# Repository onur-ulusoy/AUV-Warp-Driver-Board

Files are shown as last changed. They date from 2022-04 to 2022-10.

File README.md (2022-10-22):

# WARP Driver Board Hardware 

WARP is the dedicated motor driver and power distribution board that powers our Autonomous Underwater Vehicle (AUV). This advanced board translates high-level navigation commands into precise motor controls, while simultaneously organizes an efficient and safe power distribution network. Its built-in monitoring system and safety features provide robust defenses against potential electrical failures, ensuring the AUV can withstand the challenging underwater environment.

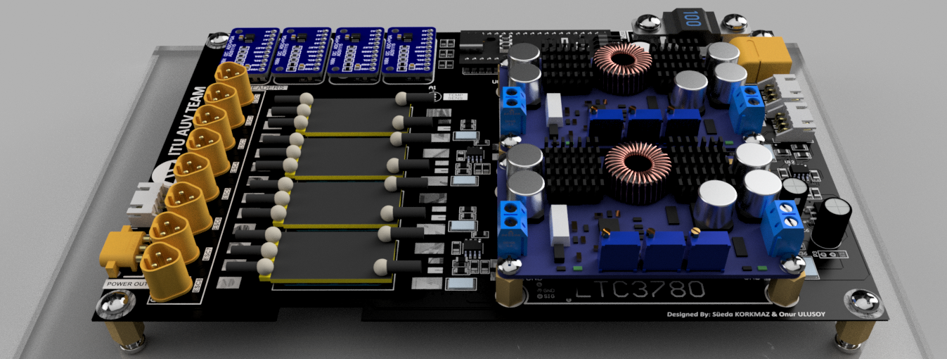
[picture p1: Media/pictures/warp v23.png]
warp
<picture>    </picture>

This repository focuses Warp's hardware design. For more details on the firmware, visit the [Warp Firmware Repository](https://github.com/onur-ulusoy/auv-warp-firmware).

<picture>   dash </picture>

<p align="center">
    <a href="https://auv.itu.edu.tr/">
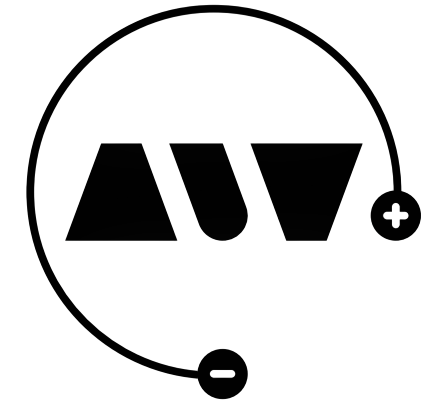
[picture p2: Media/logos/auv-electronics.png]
        
    </a>
</p>

<p align="center"><em >AUV Electronics 2022</em></p>

<picture>   dash </picture>

<p align="center">
    <a href="https://auv.itu.edu.tr/">
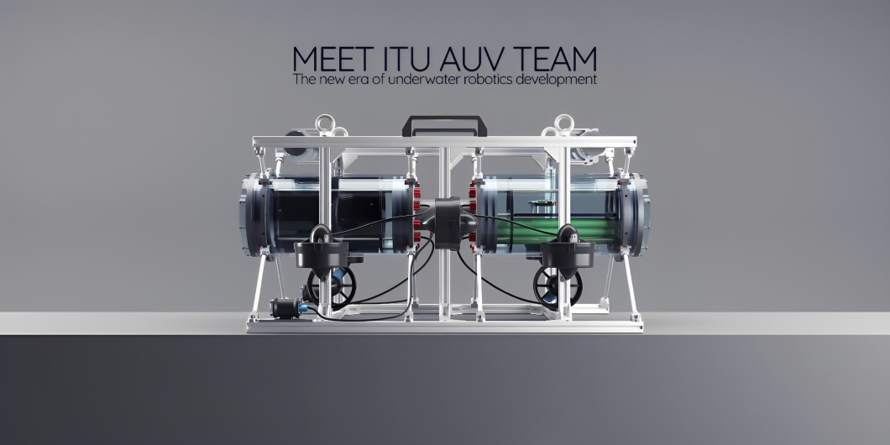
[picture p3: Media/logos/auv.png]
        
    </a>
</p>

<picture>   dash </picture>

<p align="center">
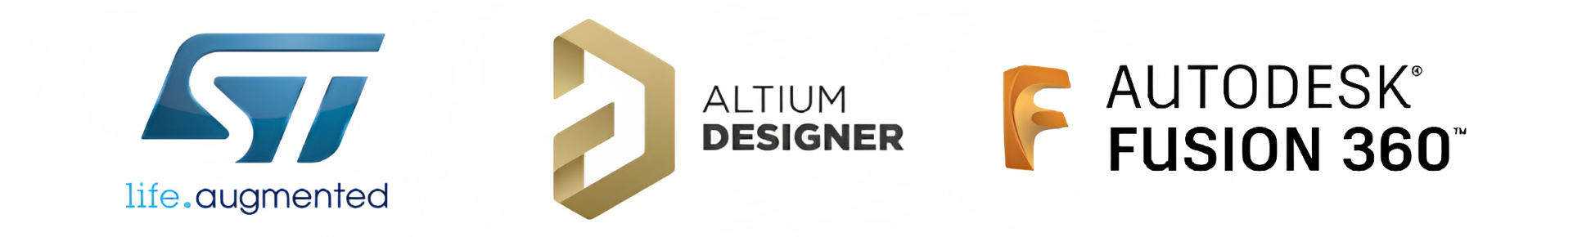
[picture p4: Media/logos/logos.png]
    
</p>

<picture>   dash </picture>

## Table of Contents
- [WARP Driver Board Hardware](#warp-driver-board-hardware)
  - [Table of Contents](#table-of-contents)
  - [Board Description](#board-description)
  - [Electronics Design](#electronics-design)
    - [Layer Structure](#layer-structure)
    - [Primary Stage Protection](#primary-stage-protection)
    - [Secondary Stage Protection](#secondary-stage-protection)
    - [Microcontroller](#microcontroller)
    - [Power Distribution](#power-distribution)
    - [Connections and Monitoring](#connections-and-monitoring)
    - [Cooling and ESC Integration](#cooling-and-esc-integration)
  - [Mechanical Architecture](#mechanical-architecture)
  - [Manufacturing](#manufacturing)
  - [Technologies Used](#technologies-used)
  - [Project Timeline](#project-timeline)
  - [License](#license)
  - [Gallery](#gallery)

## Board Description

The Warp Driver Board manages the direction movements of the underwater vehicle. It controls the brushless AC motors, connected to the propellers known as Thrusters, with PWM signals via integrated circuits called ESCs, based on commands received from the vehicle's onboard computer NVDIA Jetson Xavier. The commands are transmitted from the computer to the main board, then to the driver board, with the conversion of the UART signal to RS232 signal in the form of protobuf encrypted data.

The secondary, but equally crucial, function of the Warp Driver Board is to manage power distribution. It stabilizes the 14-16 Volt input from the battery and provides steady 12V and 5V outputs to other electronic components, the onboard computer, and various peripherals. The Warp Driver Board also includes a secondary 5V regulator to control the voltage supplied to its onboard microcontroller. 

The board is designed with safety and efficiency in mind. It includes a 100A fuse at the battery input and can measure current/voltage in various areas using integrated ADCs, thereby shutting down the vehicle in case of danger. To accurately measure voltages, it utilizes shunt resistors and voltage dividers. Critical data about current, voltage, and temperatures at key points are displayed on an LCD screen. 

## Electronics Design

For a comprehensive understanding of the WARP Driver Board's intricate design and layout, you can always visit the [Schematic Sheets](/Schematic%20Sheets/). These detailed documents will provide you with valuable insights into the structure, connections, and functionalities of the board's various components.

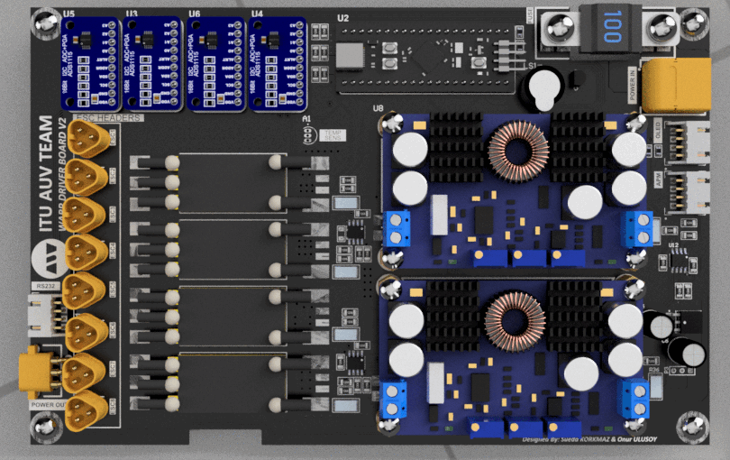
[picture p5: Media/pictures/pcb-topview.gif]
<picture>    </picture>

### Layer Structure

The WARP Driver Board features a meticulously engineered 4-layer Printed Circuit Board (PCB) structure, designed using the advanced capabilities of Altium Designer. At the heart of the layout are the power and ground layers, smartly employed as inter-layers within the design.

These inter-layers serve more than just conducting electricity or acting as a return path. Their positioning within the inner layers of the board provides a close and uniform ground plane across the board, significantly reducing loop inductance for high-speed signals. This layout strategy inherently offers enhanced signal integrity and reduces the susceptibility of the board to electromagnetic interference (EMI), which could otherwise compromise the reliability and performance of the system.

Moreover, by sandwiching the power and ground planes between the outer signal layers, the PCB achieves a better thermal management. Heat generated by components mounted on the outer layers can be efficiently spread across the plane layers and dissipated, ensuring that the board components always remain within safe operating temperatures. This design is particularly critical in a demanding application environment such as an Autonomous Underwater Vehicle, where managing thermal behavior is crucial to maintain overall system reliability and longevity.

The 4-layer structure, thus, adds significant robustness to the WARP Driver Board, enabling it to effectively support complex and power-intensive operations while ensuring optimal performance and safety.

For a more detailed examination of the board layers and the overall PCB structure, you can visit the file [WARP.PcbDoc](/WARP.PcbDoc).

### Primary Stage Protection

The design of the WARP Driver Board integrates a 100A fuse at the start of the power distribution chain, serving as the primary line of defense against overcurrent situations. Overcurrent conditions, potentially caused by short circuits, overloads, or device failures, can result in significant damage to the electronics. The fuse, meticulously calibrated to handle the high power requirements of the Autonomous Underwater Vehicle, disconnects the power supply in an overcurrent event, safeguarding all downstream circuitry and components. This strategic integration of protection measures ensures the AUV's reliability and longevity, even under challenging underwater conditions.

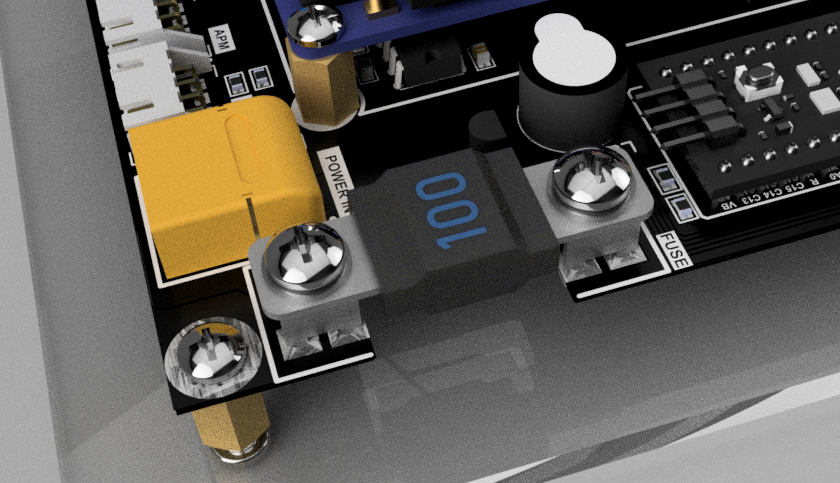
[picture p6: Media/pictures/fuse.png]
fuse
<picture>    </picture>

### Secondary Stage Protection

In addition to the primary fuse protection, the WARP Driver Board also implements a secondary stage of protective measures through its comprehensive sensing system. Critical areas on the board are monitored using advanced instrumentation circuits paired with four Analog-to-Digital Converters (ADCs).

These ADC circuits continuously monitor important parameters such as the ESC and battery voltages, currents, and ESC temperatures. This information provides a real-time overview of the board's operation and the health of its critical components.

In the event that these monitored parameters deviate from their safe operating ranges - such as experiencing overcurrent, overheating, or abnormal voltage conditions - the microcontroller is immediately alerted. Based on the severity of the deviations, the microcontroller can take appropriate actions, including throttling back operations or, in extreme cases, halting operation entirely to prevent damage.

This two-tiered approach to protection, encompassing both hardware (fuse) and software (microcontroller and sensing system) measures, enhances the safety and reliability of the WARP Driver Board. It ensures that the board can withstand a broad range of operational scenarios while minimizing the risk of component damage and system failure.

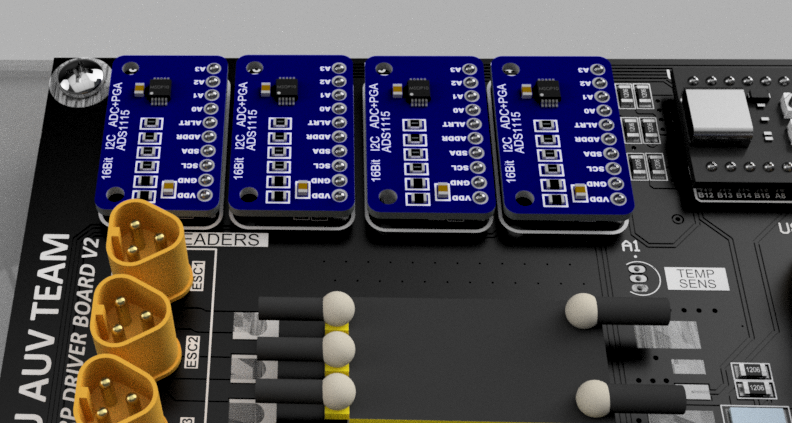
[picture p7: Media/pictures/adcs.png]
<picture>    </picture>

### Microcontroller

The WARP Driver Board's heart is an STM32 development board, strategically mounted on the top layer. It utilizes a powerful Cortex series STM32F401 microcontroller, supplying the processing power required for managing the complex tasks associated with an Autonomous Underwater Vehicle.

The microcontroller's firmware is tailored specifically for the STM32F401, enhancing control over the hardware's functionality. It integrates the FreeRTOS, a real-time operating system, enabling efficient task scheduling and management. This feature ensures that critical operations like motor driving and power monitoring are handled both coherently and responsively, thereby boosting the system's overall reliability and performance. Because this is prototype version, we used dev. board. We think embedding the microcontroller chip on the board directly in the future versions of the board.

FreeRTOS prioritizes high-importance real-time tasks, such as motor control and power management, allowing them to be addressed immediately. Lower-priority tasks are also effectively managed without compromising system performance. The harmonious combination of this firmware and real-time operating system grants the WARP Driver Board the ability to execute its key tasks with the needed precision, efficiency, and reliability.

For a deeper understanding and more detailed information and source code on the firmware, feel free to visit the [Warp Firmware Repository](https://github.com/onur-ulusoy/auv-warp-firmware).

### Power Distribution

The WARP Driver Board is equipped with various power converters and connectors, facilitating an array of power distribution options. This arrangement allows the board to cater to the different voltage requirements of the onboard peripherals, effectively supporting the diverse electronic needs of the AUV.

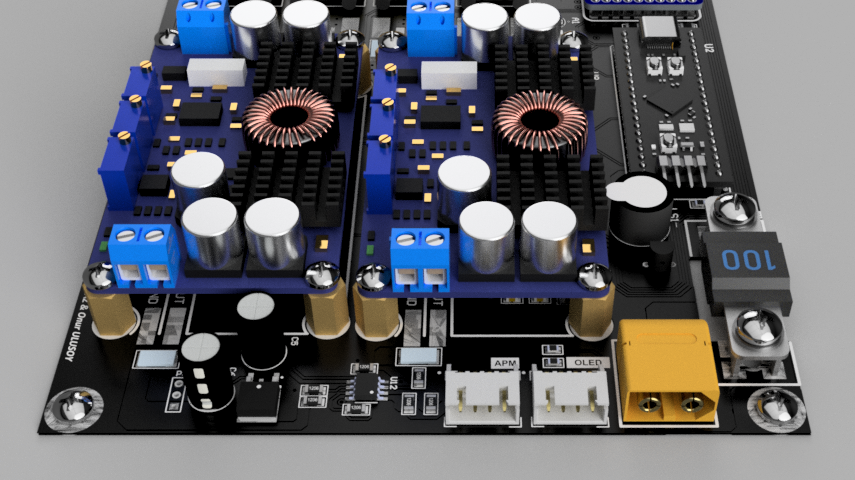
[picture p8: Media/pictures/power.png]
<picture>    </picture>

### Connections and Monitoring
The WARP Driver Board is equipped with multiple communication protocols, facilitating an efficient exchange of information within the system. It communicates with the main board using a UART interface, ensuring a seamless and reliable data exchange.

Simultaneously, the board utilizes the I2C protocol for interfacing with the ADC circuits and the OLED display. The I2C communication allows for the real-time sensing and display of vital parameters like voltages, currents, and temperatures.

Moreover, to control the thrusters, the board generates PWM signals, offering precise control over the AUV's propulsion system. This control mechanism is vital for the agile and responsive movements of the AUV in the challenging underwater environment.

For direct on-board monitoring, the board supports an OLED mountable structure, providing real-time visual data of the system's key operational parameters. This feature, coupled with its capability to transmit critical data to the main board, ensures comprehensive system surveillance and robust control.

The versatility and efficiency in communication, along with robust monitoring mechanisms, underline the WARP Driver Board's exceptional capabilities. These features, combined with an emphasis on safety and precise control, make it ideal for managing the complex requirements of an Autonomous Underwater Vehicle.

<p align="center">
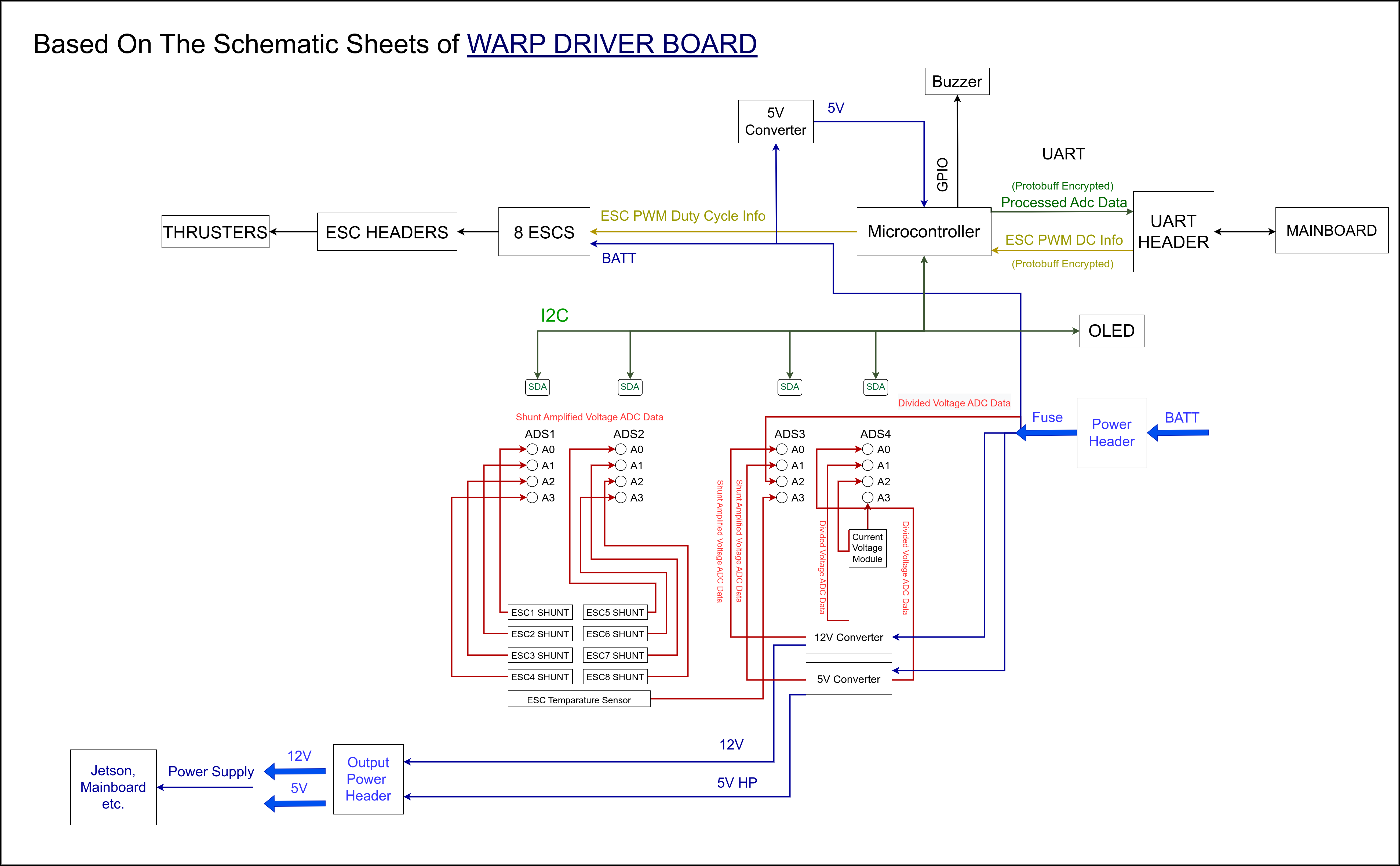
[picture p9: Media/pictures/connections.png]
    
</p>

### Cooling and ESC Integration
The WARP Driver Board uniquely integrates the Electronic Speed Controllers (ESCs) and optimizes their cooling. The ESC mount area, created with numerous vias (holes) and positioned in the coolest region of the PCB, ensures effective heat dissipation, keeping the ESCs within safe operational temperatures even during high-intensity activities.

Natural convection cooling is further enhanced during the AUV's navigation underwater, with the water flow around the ESC mount assisting in dispersing the heat. Moreover, this strategic placement allows easy access for maintenance, contributing to the system's overall reliability and lifespan.

The ESCs connect to the board through MT30-M connectors, linking them to the AUV's thrusters. They utilize BlueRobotics ESCs, specifically designed for challenging underwater conditions. This efficient design maintains ESC performance while ensuring longevity, demonstrating the board's focus on performance, durability, and maintainability.

Looking ahead, the design team is also considering the integration of a heat pipe for more advanced and efficient cooling. This future upgrade aims to further optimize the ESC's thermal management, ensuring peak performance even under heavy load conditions.

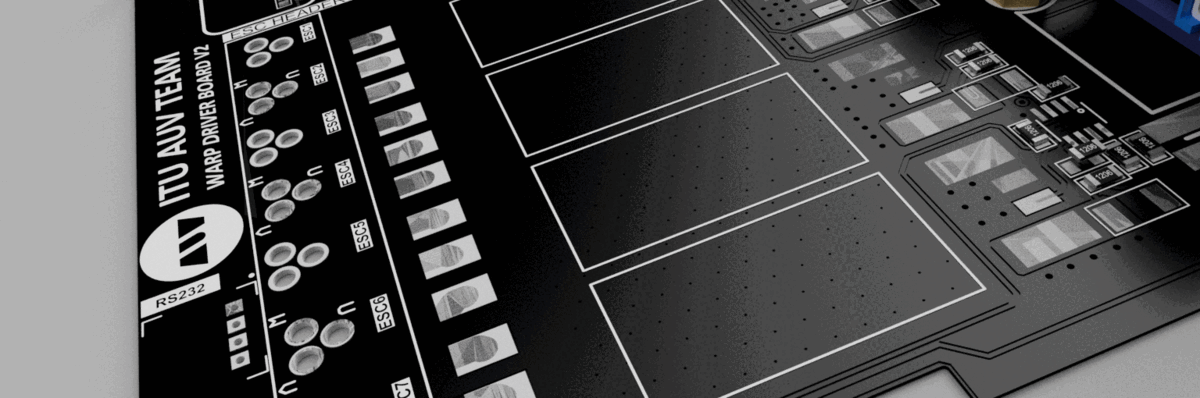
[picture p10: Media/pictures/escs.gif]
<picture>    </picture>

## Mechanical Architecture

The mechanical integration of the WARP Driver Board within the AUV has been executed with great attention to detail, ensuring stability and maximizing the use of available space. At every corner of the PCB, we've utilized standoffs and screws to secure the board to the stand, providing a sturdy and stable setup that resists vibration and shock.

Similar mounting structures have been employed for the power converters. They are secured to the PCB using standoffs and screws, maintaining their position securely even under the AUV's rigorous operating conditions.

In an innovative approach to space management, we have used pin headers to mount the ADC ICs and the microcontroller above the board. This structure elevates these components above the board, freeing up valuable space for additional SMD components.

We've also implemented a custom solution for ESC placement. The ESCs are secured with specially designed belts that are produced using 3D printing technology. This secure, custom fit ensures the ESCs stay in place while also facilitating optimal heat dissipation.

After all components are mounted, the stand is installed into the rear tube of the AUV. This process ensures the WARP Driver Board and its various components are well-protected and optimally positioned within the vehicle, demonstrating the seamless integration of mechanical and electronic design elements in the Autonomous Underwater Vehicle.

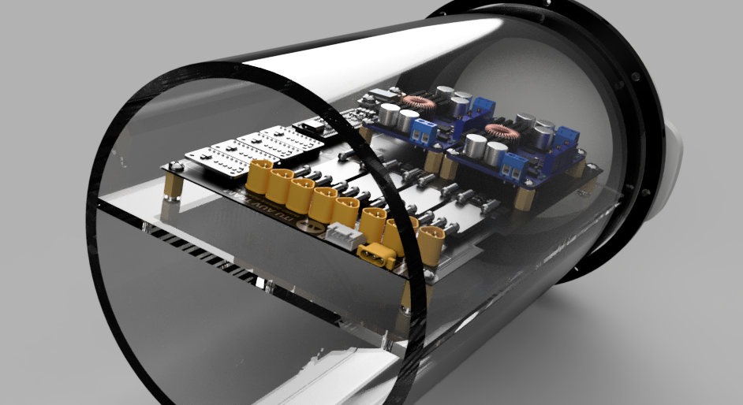
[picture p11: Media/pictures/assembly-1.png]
assembly
<picture>    </picture>

<picture>   dash </picture>

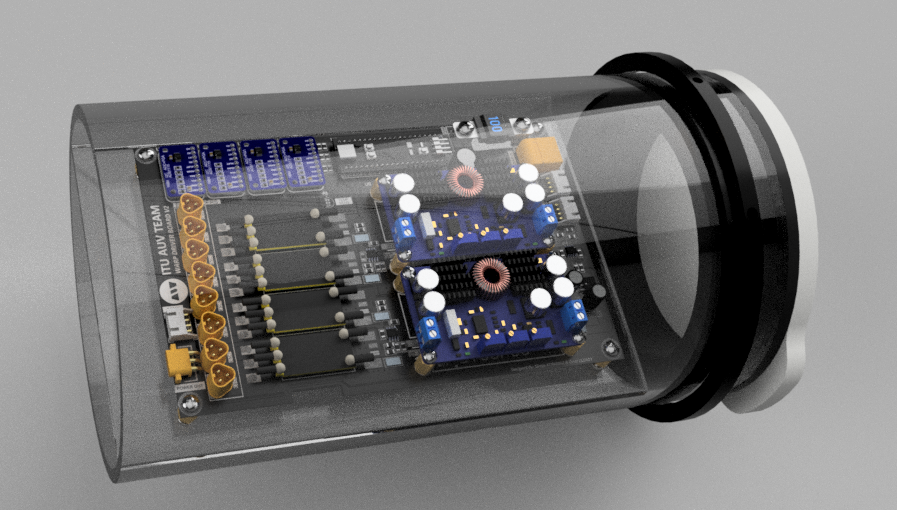
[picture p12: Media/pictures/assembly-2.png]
assembly
<picture>    </picture>

## Manufacturing 

The WARP Driver Board was designed with meticulous attention to manufacturing requirements and industry standards. We utilized the Design Rule Check (DRC) feature of Altium Designer to ensure our design adhered to the specific manufacturing specifications of our chosen PCB manufacturer, JLC PCB. You can view the details of this rule check [here](https://onur-ulusoy.github.io/AUV-Warp-Driver-Board/Output%20Files/Design%20Rule%20Check%20-%20WARP.html).

All necessary Gerber files, which provide the detailed manufacturing information required to translate our design into a physical board, are available in the [Output](/Output%20Files/) directory. 

We have manufactured and prototyped two versions of the WARP Driver Board with JLC PCB, using the feedback and insights gained from each iteration to continuously refine the design and functionality.

The final products, the manufactured boards, are currently installed on our Autonomous Underwater Vehicle and can be viewed at ITU Bisiklet Evi. This gives interested parties a chance to see our work firsthand and appreciate the tangible representation of our intricate electronics design.

## Technologies Used

- **Altium Designer:** We utilized this advanced PCB design software to craft the complex four-layer design of the board. Altium Designer's intuitive interface and comprehensive features allowed us to design and validate the board's electronic components efficiently.

- **STM Technologies:** Our system's microcontroller, the STM32 development board, comes from the STM technology suite. It forms the heart of our design, managing the sophisticated tasks within the AUV.

- **Fusion 360:** For the mechanical design and rendering of the WARP Driver Board, we used Autodesk Fusion 360. This powerful CAD/CAM tool allowed us to visualize and perfect the physical design and ensure its compatibility within the AUV. It also provides us to integrate with mechanics team.

- **Simulation Programs:** To validate and optimize our design, we made extensive use of electronic simulation programs such as Falstad and LTSpice. These tools enabled us to simulate the performance of our electronic circuits under various conditions, allowing us to refine and perfect the design before moving to manufacturing.

## Project Timeline
This project is a proud contribution of the 2022 Electronics Team of the ITU AUV (Istanbul Technical University's Autonomous Underwater Vehicle) Team. Performed in the intervals Dec 2021 - Aug 2022.

Süeda Korkmaz and Onur Ulusoy, members of the team, meticulously carried out the comprehensive design and production of PCBs and circuits using Altium Designer. Two distinct versions were manufactured with the cooperation of JLCPCB. You can visit [here](/Docs/Older%20Versions%20PCB%20Views/) for the pictures of older versions of PCB. The team also prepared and ordered all electronic components required, and undertook the detailed process of typesetting.

The PCB has found its home at the ITU Bisiklet Evi, in the AUV section of the atelier, where it has been installed on the vehicle.

We extend our gratitude towards our mindset consultant, Sencer Yazıcı, whose guidance has been instrumental throughout the process.

Onur Ulusoy's diligent efforts are to be acknowledged in providing a visually cohesive and detailed representation of our project. His work encompassed the complete set of documentation, including preparing and improving 3D models, producing high-quality renders, and ensuring effective visualization of our design.

## License



This repository contains the design and documentation for the AUV WARP Driver Board, a project by the ITU AUV Team Electonics 2022.

**Licensor:** ITU AUV Team 2022 Electronics

This work is licensed under a [Creative Commons Attribution-NonCommercial-ShareAlike 4.0 International License](http://creativecommons.org/licenses/by-nc-sa/4.0/). You can view the full terms of the license in the [LICENSE](./LICENSE) file in this repository.

**Please note:** When using this project, you must give appropriate credit, including a link to the original GitHub repository: [https://github.com/onur-ulusoy/AUV-Warp-Driver-Board](https://github.com/onur-ulusoy/AUV-Warp-Driver-Board)

## Gallery

For a visual tour of the WARP Driver Board, you can explore our [gallery](https://onur-ulusoy.github.io/AUV-Warp-Driver-Board/Media/gallery.html). Here you'll find detailed images showcasing the design and implementation of the board.

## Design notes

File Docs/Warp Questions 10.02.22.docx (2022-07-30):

2 tanesinden Coverter çıkışlarını okuduk (anlamadım) akım mı okuduk? 8 esc shunt ile aynı şekilde mi hesaplanacak akım dün dediğin gibi yani

2 tanesinden Coverter gerilim okuduk 100'e falan bölünecek mi dün opamp ile voltaj artırıyoruz demistin, bunda da var mı?

Batarya akımı ve gerilimı için de mi aynı şekilde hesaplanacak?

8 esc dışında hangileri main boarda uart ile gönderilecek?

Bu 8+2+2+2 adc inputunun alınması ve gönderilmesi hep beraber tek bir command ile mi kontrol edilecek yani hangileri birbirine bagli, hangileri bağımsız (bağımsız olanlar için ayrı adc/Dma açayım)

Bu commandler ana karttan geliyor herhalde, onların gelebilmesi için de yukarıda bahsettiğim bağımsizlık sayısına göre seri haberleşme ayarlayim (ayrıca pwm kontrolü için)

ADC/DMA ayarı

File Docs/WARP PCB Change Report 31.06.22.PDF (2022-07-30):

Change Order Report For Project | WARP.PrjPcb And WARP.PrjPcb
Action Object | Change Document | Status

Remove Pins From Nets
Remove P3- from GND | In WARP.PcbDoc | Failed to remove Pin
Remove P3- from NetP1_2 | In WARP.PcbDoc | Failed to remove Pin
Remove P3- from NetP1_3 | In WARP.PcbDoc | Failed to remove Pin
Remove U3-9 from NetP1_3 | In WARP.PcbDoc
Remove U3-10 from NetP1_2 | In WARP.PcbDoc
Remove U6- from 5V | In WARP.PcbDoc | Failed to remove Pin
Remove U6- from CONV1_SIG | In WARP.PcbDoc | Failed to remove Pin
Remove U6- from CONV2_SIG | In WARP.PcbDoc | Failed to remove Pin
Remove U6- from ESC1_PWM | In WARP.PcbDoc | Failed to remove Pin
Remove U6- from ESC2_PWM | In WARP.PcbDoc | Failed to remove Pin
Remove U6- from ESC3_PWM | In WARP.PcbDoc | Failed to remove Pin
Remove U6- from ESC4_PWM | In WARP.PcbDoc | Failed to remove Pin
Remove U6- from ESC5_PWM | In WARP.PcbDoc | Failed to remove Pin
Remove U6- from ESC6_PWM | In WARP.PcbDoc | Failed to remove Pin
Remove U6- from ESC7_PWM | In WARP.PcbDoc | Failed to remove Pin
Remove U6- from ESC8_PWM | In WARP.PcbDoc | Failed to remove Pin
Remove U6- from GND | In WARP.PcbDoc | Failed to remove Pin
Remove U6- from I2C_SCL | In WARP.PcbDoc | Failed to remove Pin
Remove U6- from I2C_SDA | In WARP.PcbDoc | Failed to remove Pin
Remove U6- from NetR7_1 | In WARP.PcbDoc | Failed to remove Pin
Remove U6- from USART1_RX | In WARP.PcbDoc | Failed to remove Pin
Remove U6- from USART1_TX | In WARP.PcbDoc | Failed to remove Pin

Remove Component Class Members
Remove R11 from U_Shunt_Current_Sense1 | In WARP.PcbDoc
Remove R15 from U_Voltage_Sense_0-30V1 | In WARP.PcbDoc
Remove R23 from U_Shunt_Current_Sense1 | In WARP.PcbDoc
Remove R24 from U_Shunt_Current_Sense2 | In WARP.PcbDoc
Remove R26 from U_Voltage_Sense_0-30V4 | In WARP.PcbDoc
Remove R32 from U_Voltage_Sense_0-30V1 | In WARP.PcbDoc
Remove R43 from U_Shunt_Current_Sense2 | In WARP.PcbDoc
Remove U5 from U_Shunt_Current_Sense5 | In WARP.PcbDoc
Remove U11 from U_Shunt_Current_Sense3 | In WARP.PcbDoc
Remove U12 from MAIN | In WARP.PcbDoc
Perşembe 30-Haz-30.2022 8:06:09 PM | Page 1 of 5

Change Component Designators
Modify | C2 -> C4 | In WARP.PcbDoc
Modify | C4 -> C2 | In WARP.PcbDoc
Modify | C7 -> C9 | In WARP.PcbDoc
Modify | C8 -> C7 | In WARP.PcbDoc
Modify | C9 -> C10 | In WARP.PcbDoc
Modify | C10 -> C8 | In WARP.PcbDoc
Modify | ESC1 -> ESC1_ESC7 | In WARP.PcbDoc
Modify | ESC2 -> ESC1_ESC5 | In WARP.PcbDoc
Modify | ESC3 -> ESC1_ESC3 | In WARP.PcbDoc
Modify | ESC4 -> ESC1_ESC1 | In WARP.PcbDoc
Modify | ESC5 -> ESC1_ESC8 | In WARP.PcbDoc
Modify | ESC6 -> ESC1_ESC6 | In WARP.PcbDoc
Modify | ESC7 -> ESC1_ESC4 | In WARP.PcbDoc
Modify | ESC8 -> ESC1_ESC2 | In WARP.PcbDoc
Modify | ESC_HEADER1 -> ESC_HEADER1_ESC8 | In WARP.PcbDoc
Modify | ESC_HEADER2 -> ESC_HEADER1_ESC6 | In WARP.PcbDoc
Modify | ESC_HEADER3 -> ESC_HEADER1_ESC4 | In WARP.PcbDoc
Modify | ESC_HEADER4 -> ESC_HEADER1_ESC2 | In WARP.PcbDoc
Modify | ESC_HEADER5 -> ESC_HEADER1_ESC7 | In WARP.PcbDoc
Modify | ESC_HEADER6 -> ESC_HEADER1_ESC5 | In WARP.PcbDoc
Modify | ESC_HEADER7 -> ESC_HEADER1_ESC3 | In WARP.PcbDoc
Modify | ESC_HEADER8 -> ESC_HEADER1_ESC1 | In WARP.PcbDoc
Modify | P1 -> P3 | In WARP.PcbDoc
Modify | P3 -> P1 | In WARP.PcbDoc
Modify | Q1 -> Q2 | In WARP.PcbDoc
Modify | Q2 -> Q3 | In WARP.PcbDoc
Modify | Q3 -> Q1 | In WARP.PcbDoc
Modify | R1 -> R22_U_Shunt_Current_Sense1 | In WARP.PcbDoc
Modify | R2 -> R22_U_Shunt_Current_Sense2 | In WARP.PcbDoc
Modify | R3 -> R24_U_Voltage_Sense_0-30V1 | In WARP.PcbDoc
Modify | R4 -> R21_U_Shunt_Current_Sense1 | In WARP.PcbDoc
Modify | R5 -> R21_U_Shunt_Current_Sense2 | In WARP.PcbDoc
Modify | R6 -> R23_U_Voltage_Sense_0-30V1 | In WARP.PcbDoc
Modify | R7 -> R20_U_Shunt_Current_Sense1 | In WARP.PcbDoc
Modify | R8 -> R20_U_Shunt_Current_Sense2 | In WARP.PcbDoc
Modify | R9 -> R13_U_Shunt_Current_Sense4 | In WARP.PcbDoc
Modify | R10 -> R23_U_Voltage_Sense_0-30V4 | In WARP.PcbDoc
Modify | R11 -> R4 | In WARP.PcbDoc
Modify | R12 -> R3 | In WARP.PcbDoc
Modify | R13 -> R19_U_Shunt_Current_Sense1 | In WARP.PcbDoc
Modify | R14 -> R19_U_Shunt_Current_Sense2 | In WARP.PcbDoc
Modify | R15 -> R6 | In WARP.PcbDoc
Modify | R16 -> R15_U_Shunt_Current_Sense3 | In WARP.PcbDoc
Modify | R17 -> R20_U_Shunt_Current_Sense3 | In WARP.PcbDoc
Modify | R18 -> R5 | In WARP.PcbDoc
Modify | R19 -> R18_U_Shunt_Current_Sense1 | In WARP.PcbDoc
Modify | R20 -> R18_U_Shunt_Current_Sense2 | In WARP.PcbDoc
Modify | R21 -> R16_U_Shunt_Current_Sense3 | In WARP.PcbDoc
Modify | R22 -> R11 | In WARP.PcbDoc
Modify | R23 -> R1 | In WARP.PcbDoc
Modify | R24 -> R2 | In WARP.PcbDoc
Modify | R25 -> R21_U_Shunt_Current_Sense3 | In WARP.PcbDoc
Modify | R26 -> R10 | In WARP.PcbDoc
Modify | R27 -> R9 | In WARP.PcbDoc
Modify | R28 -> R19_U_Shunt_Current_Sense3 | In WARP.PcbDoc
Modify | R29 -> R17_U_Shunt_Current_Sense3 | In WARP.PcbDoc
Modify | R30 -> R17_U_Shunt_Current_Sense1 | In WARP.PcbDoc
Modify | R31 -> R17_U_Shunt_Current_Sense2 | In WARP.PcbDoc
Modify | R32 -> R12 | In WARP.PcbDoc
Modify | R33 -> R18_U_Shunt_Current_Sense3 | In WARP.PcbDoc
Modify | R34 -> R13_U_Shunt_Current_Sense3 | In WARP.PcbDoc
Modify | R35 -> R21_U_Shunt_Current_Sense5 | In WARP.PcbDoc
Modify | R36 -> R19_U_Shunt_Current_Sense5 | In WARP.PcbDoc
Modify | R37 -> R14_U_Shunt_Current_Sense3 | In WARP.PcbDoc
Modify | R38 -> R22_U_Shunt_Current_Sense3 | In WARP.PcbDoc
Modify | R39 -> R16_U_Shunt_Current_Sense1 | In WARP.PcbDoc
Modify | R40 -> R17_U_Shunt_Current_Sense5 | In WARP.PcbDoc
Modify | R41 -> R7 | In WARP.PcbDoc
Modify | R42 -> R16_U_Shunt_Current_Sense2 | In WARP.PcbDoc

Change Component Designators
Modify | R43 -> R8 | In WARP.PcbDoc
Modify | R44 -> R15_U_Shunt_Current_Sense1 | In WARP.PcbDoc
Modify | R45 -> R15_U_Shunt_Current_Sense2 | In WARP.PcbDoc
Modify | R46 -> R23_U_Voltage_Sense_0-30V3 | In WARP.PcbDoc
Modify | R47 -> R14_U_Shunt_Current_Sense1 | In WARP.PcbDoc
Modify | R48 -> R14_U_Shunt_Current_Sense4 | In WARP.PcbDoc
Modify | R49 -> R14_U_Shunt_Current_Sense5 | In WARP.PcbDoc
Modify | R50 -> R13_U_Shunt_Current_Sense5 | In WARP.PcbDoc
Modify | R51 -> R21_U_Shunt_Current_Sense4 | In WARP.PcbDoc
Modify | R52 -> R14_U_Shunt_Current_Sense2 | In WARP.PcbDoc
Modify | R53 -> R20_U_Shunt_Current_Sense5 | In WARP.PcbDoc
Modify | R54 -> R15_U_Shunt_Current_Sense4 | In WARP.PcbDoc
Modify | R55 -> R16_U_Shunt_Current_Sense4 | In WARP.PcbDoc
Modify | R56 -> R22_U_Shunt_Current_Sense4 | In WARP.PcbDoc
Modify | R57 -> R20_U_Shunt_Current_Sense4 | In WARP.PcbDoc
Modify | R58 -> R19_U_Shunt_Current_Sense4 | In WARP.PcbDoc
Modify | R59 -> R24_U_Voltage_Sense_0-30V2 | In WARP.PcbDoc
Modify | R60 -> R16_U_Shunt_Current_Sense5 | In WARP.PcbDoc
Modify | R61 -> R23_U_Voltage_Sense_0-30V2 | In WARP.PcbDoc
Modify | R62 -> R22_U_Shunt_Current_Sense5 | In WARP.PcbDoc
Modify | R63 -> R15_U_Shunt_Current_Sense5 | In WARP.PcbDoc
Modify | R64 -> R24_U_Voltage_Sense_0-30V4 | In WARP.PcbDoc
Modify | R65 -> R24_U_Voltage_Sense_0-30V3 | In WARP.PcbDoc
Modify | R66 -> R18_U_Shunt_Current_Sense4 | In WARP.PcbDoc
Modify | R67 -> R17_U_Shunt_Current_Sense4 | In WARP.PcbDoc
Modify | R68 -> R18_U_Shunt_Current_Sense5 | In WARP.PcbDoc
Modify | R69 -> R13_U_Shunt_Current_Sense1 | In WARP.PcbDoc
Modify | R70 -> R13_U_Shunt_Current_Sense2 | In WARP.PcbDoc
Modify | U1 -> U3 | In WARP.PcbDoc
Modify | U3 -> U5 | In WARP.PcbDoc
Modify | U5 -> U9 | In WARP.PcbDoc
Modify | U6 -> U1 | In WARP.PcbDoc
Modify | U9 -> U11_U_Shunt_Current_Sense5 | In WARP.PcbDoc
Modify | U10 -> U11_U_Shunt_Current_Sense3 | In WARP.PcbDoc
Modify | U11 -> U10 | In WARP.PcbDoc
Modify | U12 -> U6 | In WARP.PcbDoc
Modify | U13 -> U11_U_Shunt_Current_Sense4 | In WARP.PcbDoc
Modify | U14 -> U11_U_Shunt_Current_Sense1 | In WARP.PcbDoc
Modify | U15 -> U11_U_Shunt_Current_Sense2 | In WARP.PcbDoc

Add Pins To Nets
Add | P1-1 to GND | In WARP.PcbDoc | Unknown Pin: Pin P1-1
Add | P1-2 to NetP1_2 | In WARP.PcbDoc | Unknown Pin: Pin P1-2
Add | P1-3 to NetP1_3 | In WARP.PcbDoc | Unknown Pin: Pin P1-3
Add | U1-5 to ESC3_PWM | In WARP.PcbDoc | Unknown Pin: Pin U1-5
Add | U1-6 to USART1_TX | In WARP.PcbDoc | Unknown Pin: Pin U1-6
Add | U1-7 to USART1_RX | In WARP.PcbDoc | Unknown Pin: Pin U1-7
Add | U1-10 to ESC4_PWM | In WARP.PcbDoc | Unknown Pin: Pin U1-10
Add | U1-11 to ESC5_PWM | In WARP.PcbDoc | Unknown Pin: Pin U1-11
Add | U1-12 to ESC2_PWM | In WARP.PcbDoc | Unknown Pin: Pin U1-12
Add | U1-13 to ESC6_PWM | In WARP.PcbDoc | Unknown Pin: Pin U1-13
Add | U1-14 to I2C_SCL | In WARP.PcbDoc | Unknown Pin: Pin U1-14
Add | U1-15 to I2C_SDA | In WARP.PcbDoc | Unknown Pin: Pin U1-15
Add | U1-16 to ESC8_PWM | In WARP.PcbDoc | Unknown Pin: Pin U1-16
Add | U1-17 to ESC7_PWM | In WARP.PcbDoc | Unknown Pin: Pin U1-17
Add | U1-18 to 5V | In WARP.PcbDoc | Unknown Pin: Pin U1-18
Add | U1-19 to GND | In WARP.PcbDoc | Unknown Pin: Pin U1-19
Add | U1-22 to CONV1_SIG | In WARP.PcbDoc | Unknown Pin: Pin U1-22
Add | U1-23 to NetR7_1 | In WARP.PcbDoc | Unknown Pin: Pin U1-23
Add | U1-36 to CONV2_SIG | In WARP.PcbDoc | Unknown Pin: Pin U1-36
Add | U1-37 to ESC1_PWM | In WARP.PcbDoc | Unknown Pin: Pin U1-37
Add | U1-39 to GND | In WARP.PcbDoc | Unknown Pin: Pin U1-39
Add | U5-9 to NetP1_2 | In WARP.PcbDoc
Add | U5-10 to NetP1_3 | In WARP.PcbDoc

Add Component Class Members
Add | C4 to MAIN | In WARP.PcbDoc
Add | C7 to U_RS232 | In WARP.PcbDoc
Add | C10 to U_RS232 | In WARP.PcbDoc
Add | Q3 to MAIN | In WARP.PcbDoc
Add | R3 to MAIN | In WARP.PcbDoc
Add | R20_U_Shunt_Current_Sense2 to | In WARP.PcbDoc
| U_Shunt_Current_Sense2
Add | R21_U_Shunt_Current_Sense1 to | In WARP.PcbDoc
| U_Shunt_Current_Sense1
Add | R22_U_Shunt_Current_Sense1 to | In WARP.PcbDoc
| U_Shunt_Current_Sense1
Add | R22_U_Shunt_Current_Sense2 to | In WARP.PcbDoc
| U_Shunt_Current_Sense2
Add | R23_U_Voltage_Sense_0-30V1 to | In WARP.PcbDoc
| U_Voltage_Sense_0-30V1
Add | R23_U_Voltage_Sense_0-30V4 to | In WARP.PcbDoc
| U_Voltage_Sense_0-30V4
Add | R24_U_Voltage_Sense_0-30V1 to | In WARP.PcbDoc
| U_Voltage_Sense_0-30V1
Add | U1 to MAIN | In WARP.PcbDoc
Add | U5 to MAIN | In WARP.PcbDoc
Add | U11_U_Shunt_Current_Sense3 to | In WARP.PcbDoc
| U_Shunt_Current_Sense3
Add | U11_U_Shunt_Current_Sense5 to | In WARP.PcbDoc
| U_Shunt_Current_Sense5

Add Rooms
Add Room ESC1 (Scope=InComponentClass('ESC1')) To WARP.PcbDoc TopLayer
Add Room ESC2 (Scope=InComponentClass('ESC2')) To WARP.PcbDoc TopLayer
Add Room ESC3 (Scope=InComponentClass('ESC3')) To WARP.PcbDoc TopLayer
Add Room ESC4 (Scope=InComponentClass('ESC4')) To WARP.PcbDoc TopLayer
Add Room ESC5 (Scope=InComponentClass('ESC5')) To WARP.PcbDoc TopLayer
Add Room ESC6 (Scope=InComponentClass('ESC6')) To WARP.PcbDoc TopLayer
Add Room ESC7 (Scope=InComponentClass('ESC7')) To WARP.PcbDoc TopLayer
Add Room ESC8 (Scope=InComponentClass('ESC8')) To WARP.PcbDoc TopLayer
Add Room MAIN (Scope=InComponentClass('MAIN')) To WARP.PcbDoc TopLayer
Add | Room U_POWER | To WARP.PcbDoc
| (Scope=InComponentClass('U_POWER')) TopLayer
Add | Room U_RS232 | To WARP.PcbDoc
| (Scope=InComponentClass('U_RS232')) TopLayer
Add | Room U_Shunt_Current_Sense1(Scope=InCompo To WARP.PcbDoc
| nentClass('U_Shunt_Current_Sense1')) TopLayer
Add | Room U_Shunt_Current_Sense2(Scope=InCompo To WARP.PcbDoc
| nentClass('U_Shunt_Current_Sense2')) TopLayer
Add | Room U_Shunt_Current_Sense3(Scope=InCompo To WARP.PcbDoc
| nentClass('U_Shunt_Current_Sense3')) TopLayer
Add | Room U_Shunt_Current_Sense4(Scope=InCompo To WARP.PcbDoc
| nentClass('U_Shunt_Current_Sense4')) TopLayer
Add | Room U_Shunt_Current_Sense5(Scope=InCompo To WARP.PcbDoc
| nentClass('U_Shunt_Current_Sense5')) TopLayer
Add | Room U_Voltage_Sense_0-30V1(Scope=InComp To WARP.PcbDoc
| onentClass('U_Voltage_Sense_0-30V1')) TopLayer
Add | Room U_Voltage_Sense_0-30V2(Scope=InComp To WARP.PcbDoc
| onentClass('U_Voltage_Sense_0-30V2')) TopLayer
Add | Room U_Voltage_Sense_0-30V3(Scope=InComp To WARP.PcbDoc
| onentClass('U_Voltage_Sense_0-30V3')) TopLayer
Add | Room U_Voltage_Sense_0-30V4(Scope=InComp To WARP.PcbDoc
| onentClass('U_Voltage_Sense_0-30V4')) TopLayer

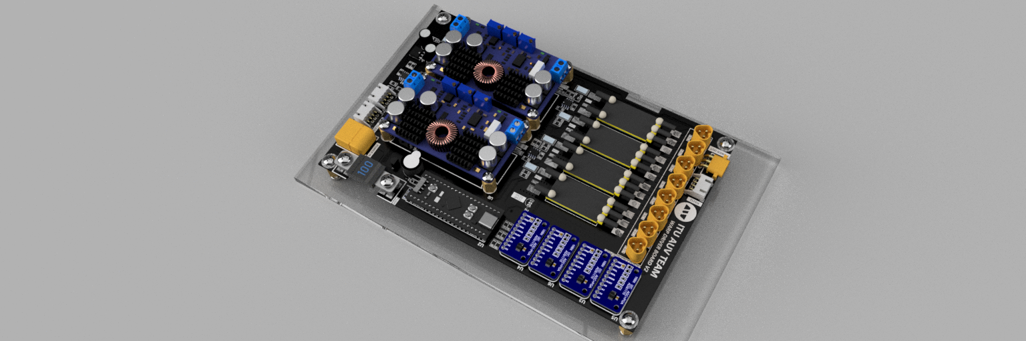
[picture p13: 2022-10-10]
Media/pictures/perspective-1.png

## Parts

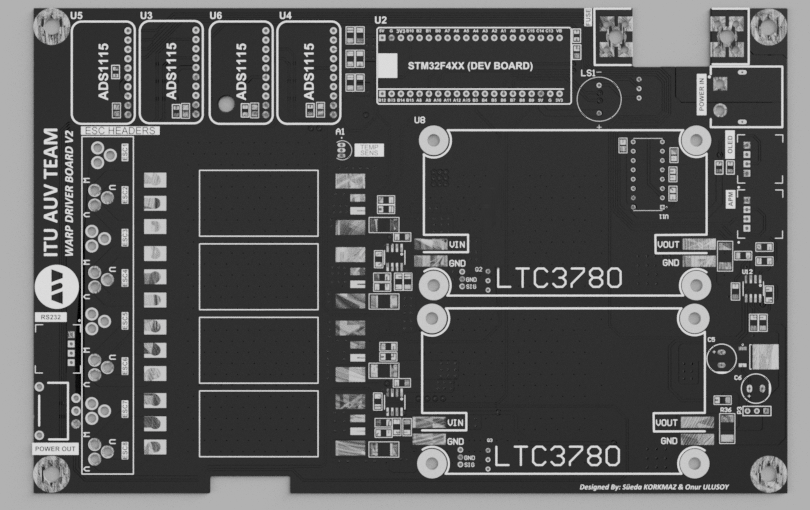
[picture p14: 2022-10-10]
Media/pictures/pcb-topview-without-components.png

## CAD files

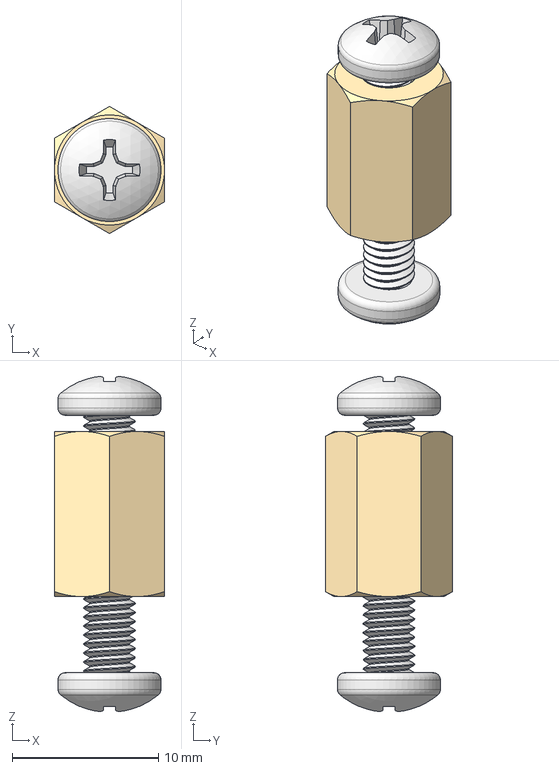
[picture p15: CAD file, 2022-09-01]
3D Models/Assemblies/standoff assembly 2 v3.step
7.52 x 8.69 x 22.9 mm
90012A230_Aluminum Coupling Nut
96741A218_Brass Pan Head Phillips Screws x 2

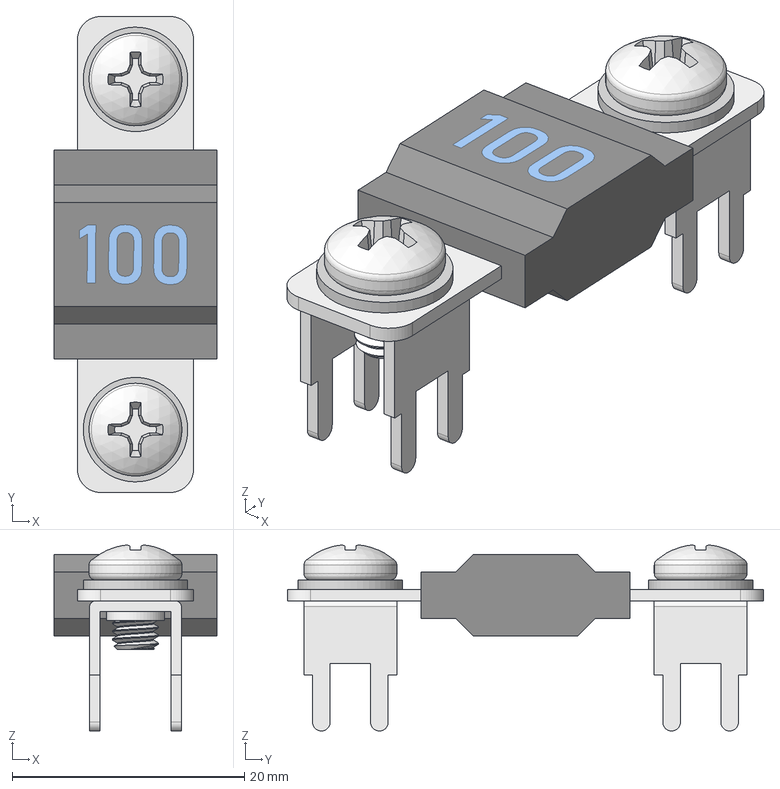
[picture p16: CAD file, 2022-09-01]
3D Models/Assemblies/fuse assembly no pcb v2.step
14.0 x 41.0 x 16.0 mm
100 anlfuse
94102A137_JIS Stainless Steel Pan Head Screws x 2
90718A140_Electrical-Insulating Nylon Washer x 2

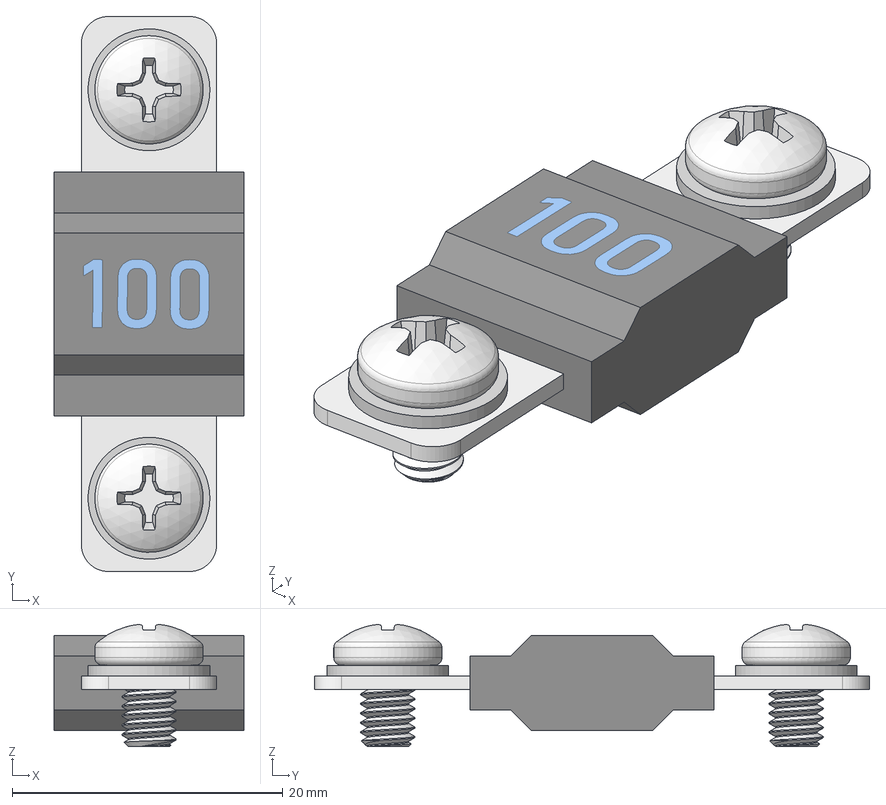
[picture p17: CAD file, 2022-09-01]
3D Models/Assemblies/fuse assembly no pcb no support v2.step
14.0 x 41.0 x 9.01 mm
100 anlfuse
94102A137_JIS Stainless Steel Pan Head Screws x 2
90718A140_Electrical-Insulating Nylon Washer x 2

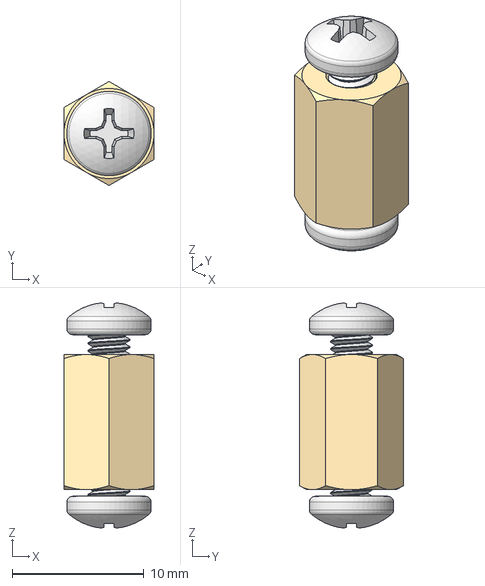
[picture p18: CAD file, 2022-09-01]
3D Models/Assemblies/standoff assembly v10.step
6.84 x 7.90 x 17.1 mm
90012A230_Aluminum Coupling Nut
96741A218_Brass Pan Head Phillips Screws x 2

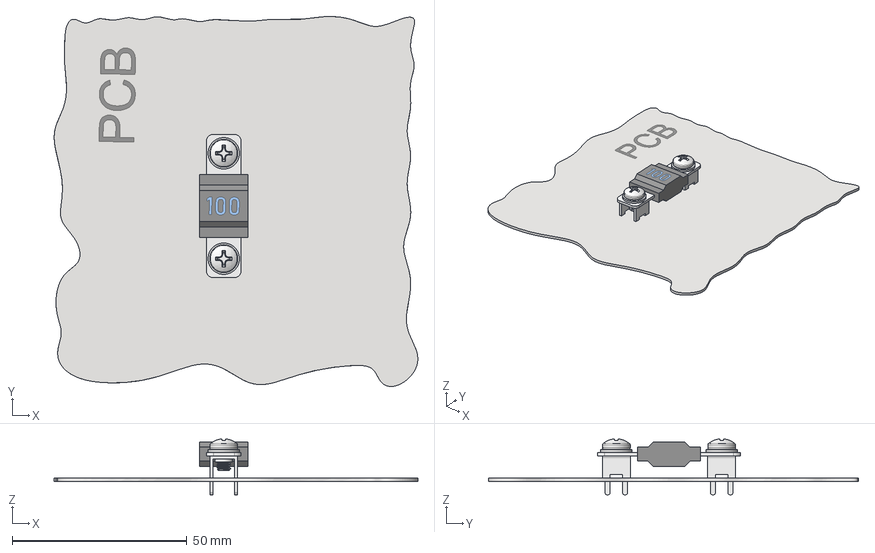
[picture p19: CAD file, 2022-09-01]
3D Models/Assemblies/fuse assembly v8.step
104.1 x 105.9 x 16.0 mm
pcb
100 anlfuse
94102A137_JIS Stainless Steel Pan Head Screws x 2
90718A140_Electrical-Insulating Nylon Washer x 2

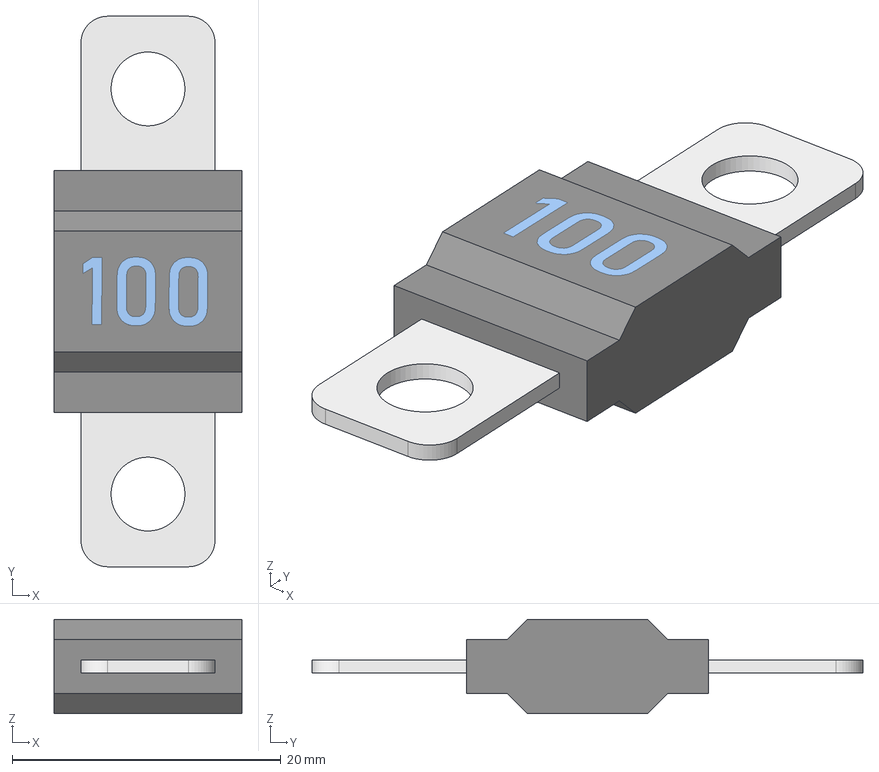
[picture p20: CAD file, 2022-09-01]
3D Models/Components/100 anlfuse v4.step
14.0 x 41.0 x 7.00 mm

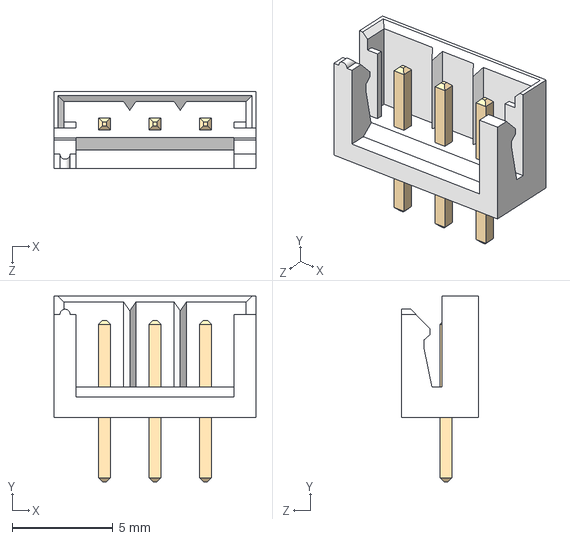
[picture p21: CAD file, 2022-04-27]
3D Models/Connectors/EH 2.50 connectors/STEP/BB-Top_Entry_Type/JST-B3B-EH-A.STEP
10.0 x 9.20 x 3.80 mm

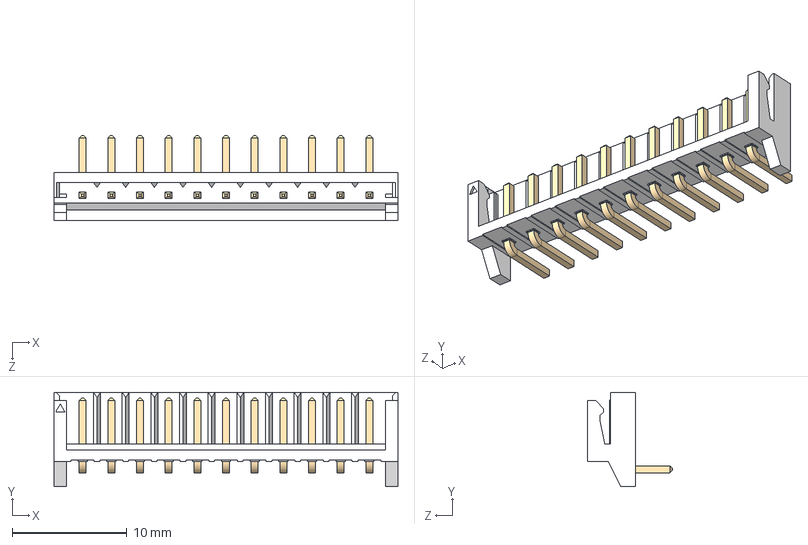
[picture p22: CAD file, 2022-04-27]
3D Models/Connectors/EH 2.50 connectors/STEP/SB-Side_Entry_Type/JST-S11B-EH-A.STEP
30.0 x 8.20 x 7.40 mm

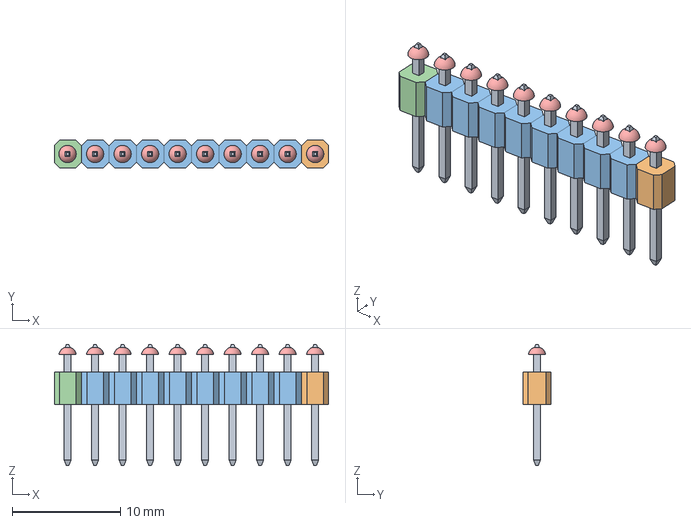
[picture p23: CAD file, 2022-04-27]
3D Models/Connectors/Male Header v4.step
25.3 x 2.54 x 11.2 mm

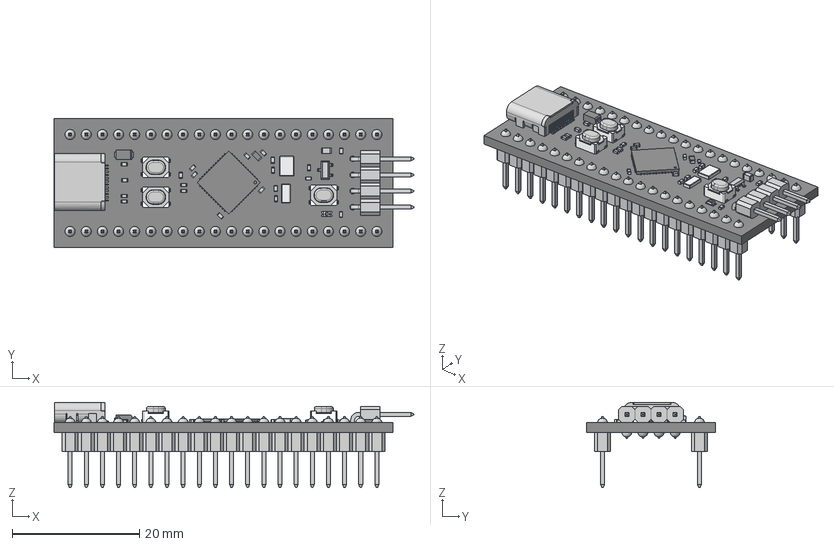
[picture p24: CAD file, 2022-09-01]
3D Models/Components/stm32f401 v2.step
56.6 x 20.3 x 13.4 mm
Board_001
STM32F4 Chip_001
Surface Mount Transistor_001
0603 Resistor_001
0603 Capacitor_001
0402 Capacitor_001
0402 Resistor_001
0402 Resistor_002
0402 Resistor_003
0402 Resistor_004
0402 Resistor_005
0402 Resistor_006
0402 Resistor_007
0402 Resistor_008
0402 Capacitor_002
0402 Capacitor_003
0402 Capacitor_004
0402 Capacitor_005
0402 Capacitor_006
0402 Capacitor_007
0402 Capacitor_008
0402 Capacitor_009
0402 Capacitor_010
0402 Capacitor_011
0402 Capacitor_012
0402 Capacitor_013
Diode 2_001
SM LED_001
1x20 Male Header_001
1x20 Male Header_002
Tac Switch_001
Tac Switch_002
Tac Switch_003
USB-C Connector_001
1x4 Right Angle Male Header_001
Crystal 1_001
Crystal 2_001

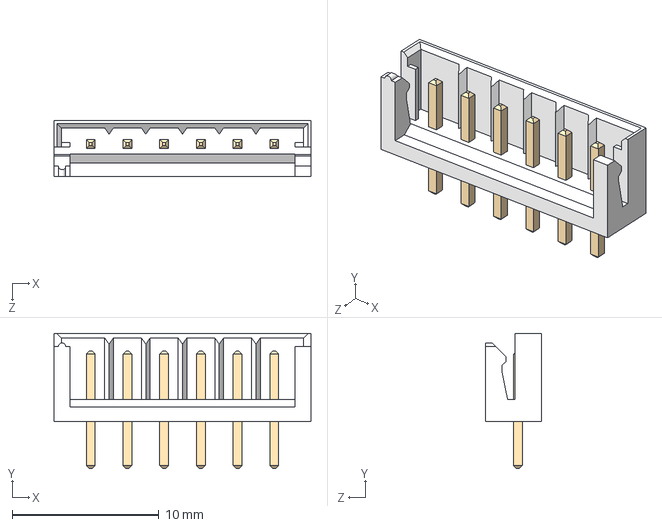
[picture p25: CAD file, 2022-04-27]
3D Models/Connectors/EH 2.50 connectors/STEP/BB-Top_Entry_Type/JST-B6B-EH-A.STEP
17.5 x 9.20 x 3.80 mm

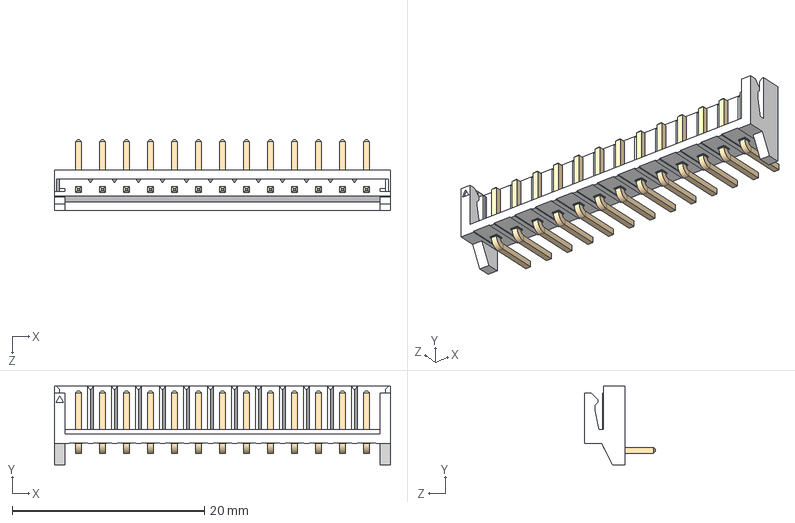
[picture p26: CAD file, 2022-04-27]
3D Models/Connectors/EH 2.50 connectors/STEP/SB-Side_Entry_Type/JST-S13B-EH-A.STEP
35.0 x 8.20 x 7.40 mm

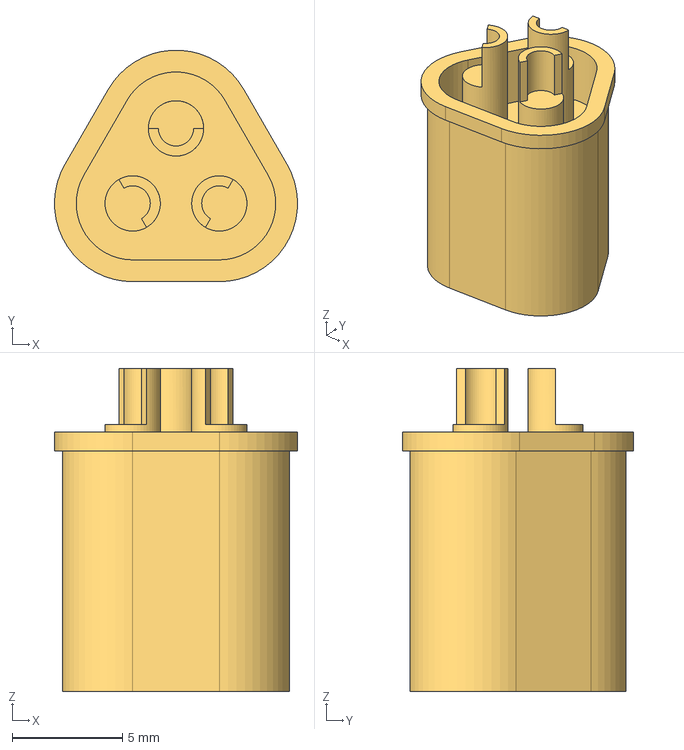
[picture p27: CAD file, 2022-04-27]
3D Models/Connectors/mt30-m connector v2.step
11.0 x 10.5 x 14.7 mm

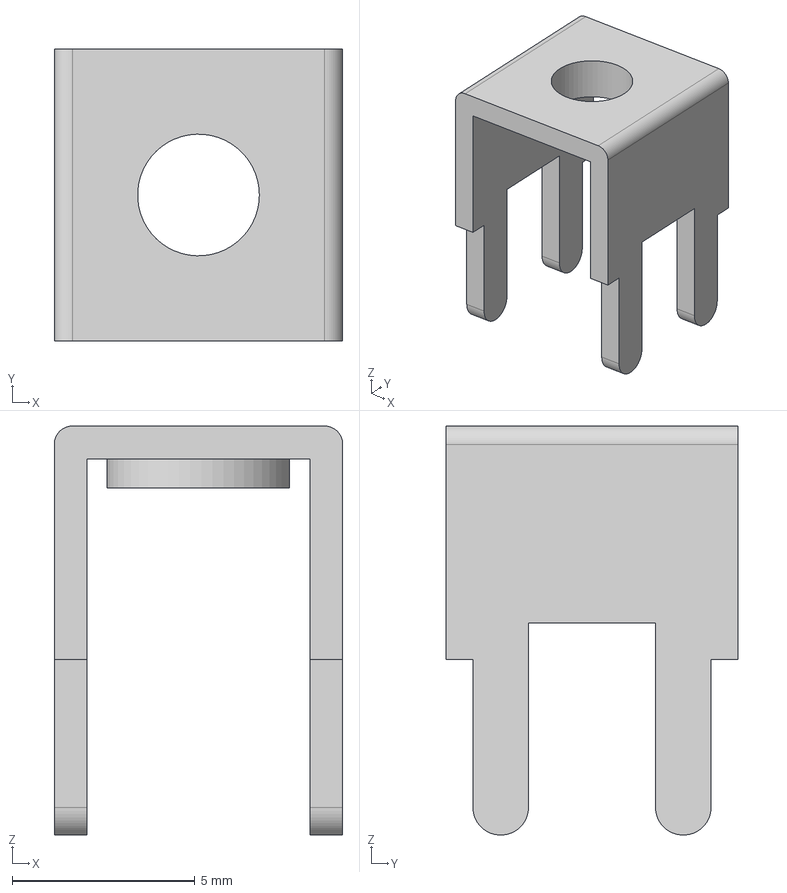
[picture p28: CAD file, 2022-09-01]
3D Models/Components/fuse support v1.step
7.90 x 8.00 x 11.2 mm

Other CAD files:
3D Models/Connectors/EH 2.50 connectors/STEP/BB-Top_Entry_Type/JST-B9B-EH-A.STEP
3D Models/Connectors/EH 2.50 connectors/STEP/SB-Side_Entry_Type/JST-S8B-EH-A.STEP
3D Models/Connectors/mr30pw-m connector v2.step
3D Models/Components/BESC30-R3 v1.step
3D Models/Components/SMD_0805LED_YEL v2.step
3D Models/Components/resistor_smd_1206 v13.step
3D Models/Connectors/EH 2.50 connectors/SOURCE/BB-Top_Entry_Type/JST-B2B-EH-A.SLDPRT
3D Models/Connectors/EH 2.50 connectors/SOURCE/BB-Top_Entry_Type/JST-B3B-EH-A.SLDPRT
3D Models/Connectors/EH 2.50 connectors/SOURCE/SB-Side_Entry_Type/JST-S2B-EH-A.SLDPRT
3D Models/Connectors/EH 2.50 connectors/SOURCE/SB-Side_Entry_Type/JST-S3B-EH-A.SLDPRT
3D Models/Connectors/EH 2.50 connectors/STEP/BB-Top_Entry_Type/JST-B10B-EH-A.STEP
3D Models/Connectors/EH 2.50 connectors/STEP/BB-Top_Entry_Type/JST-B11B-EH-A.STEP
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

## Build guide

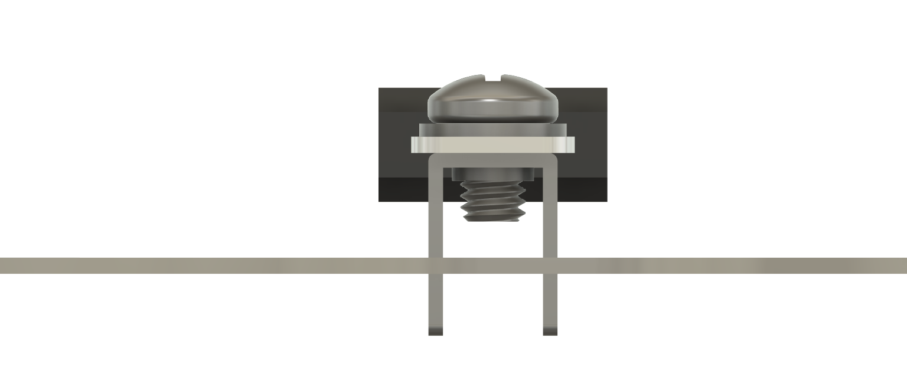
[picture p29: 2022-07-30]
Docs/fuse assembly sol.png

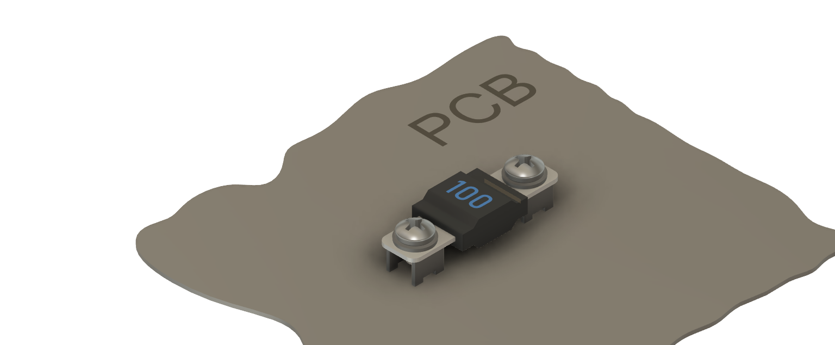
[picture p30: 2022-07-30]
Docs/fuse assembly.png

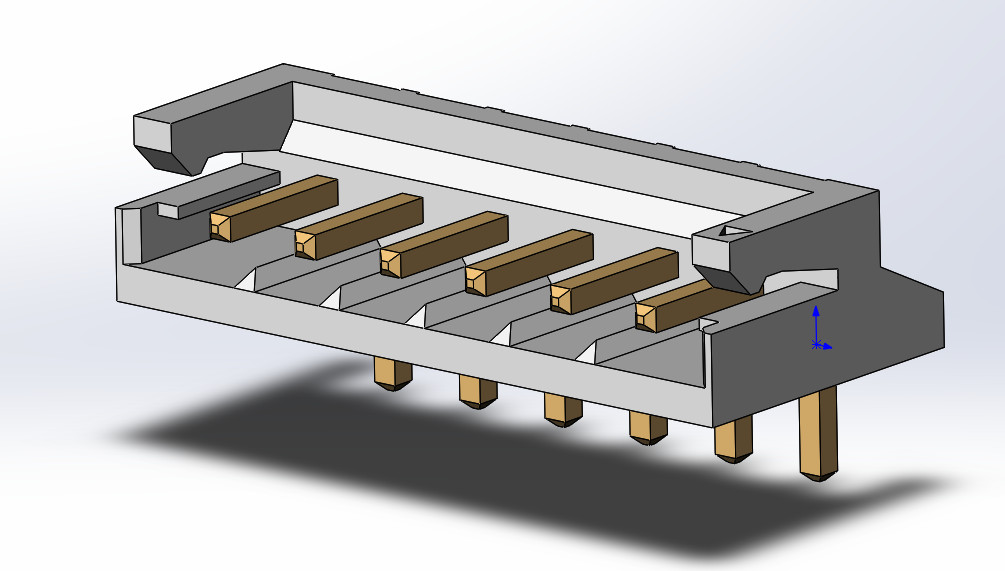
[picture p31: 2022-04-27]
3D Models/Connectors/EH 2.50 connectors/STEP/SB-Side_Entry_Type/a-JST-SxB-EH-A.JPG

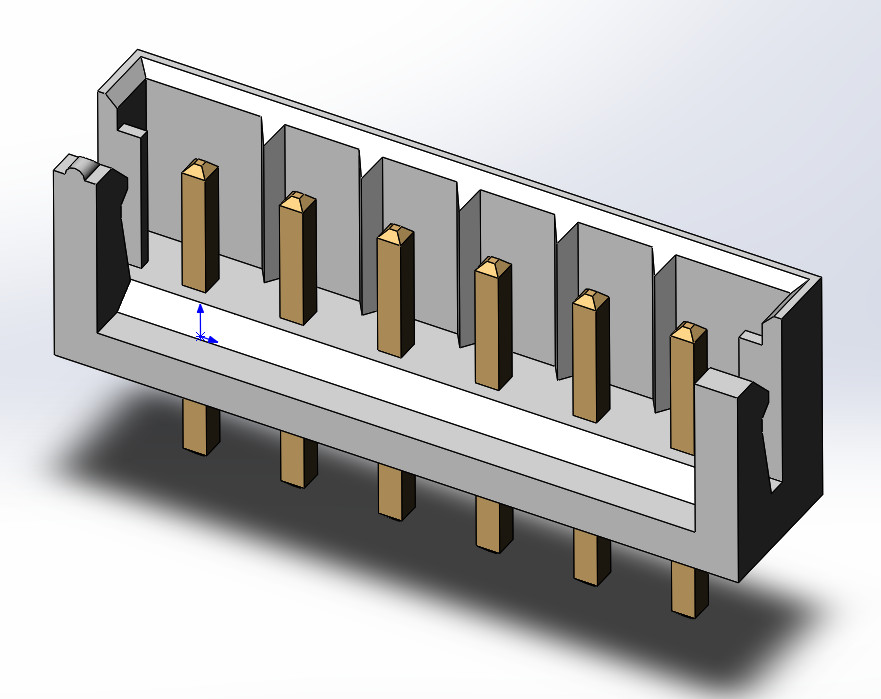
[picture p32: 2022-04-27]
3D Models/Connectors/EH 2.50 connectors/STEP/BB-Top_Entry_Type/a-JST-BxB-EH-A.JPG

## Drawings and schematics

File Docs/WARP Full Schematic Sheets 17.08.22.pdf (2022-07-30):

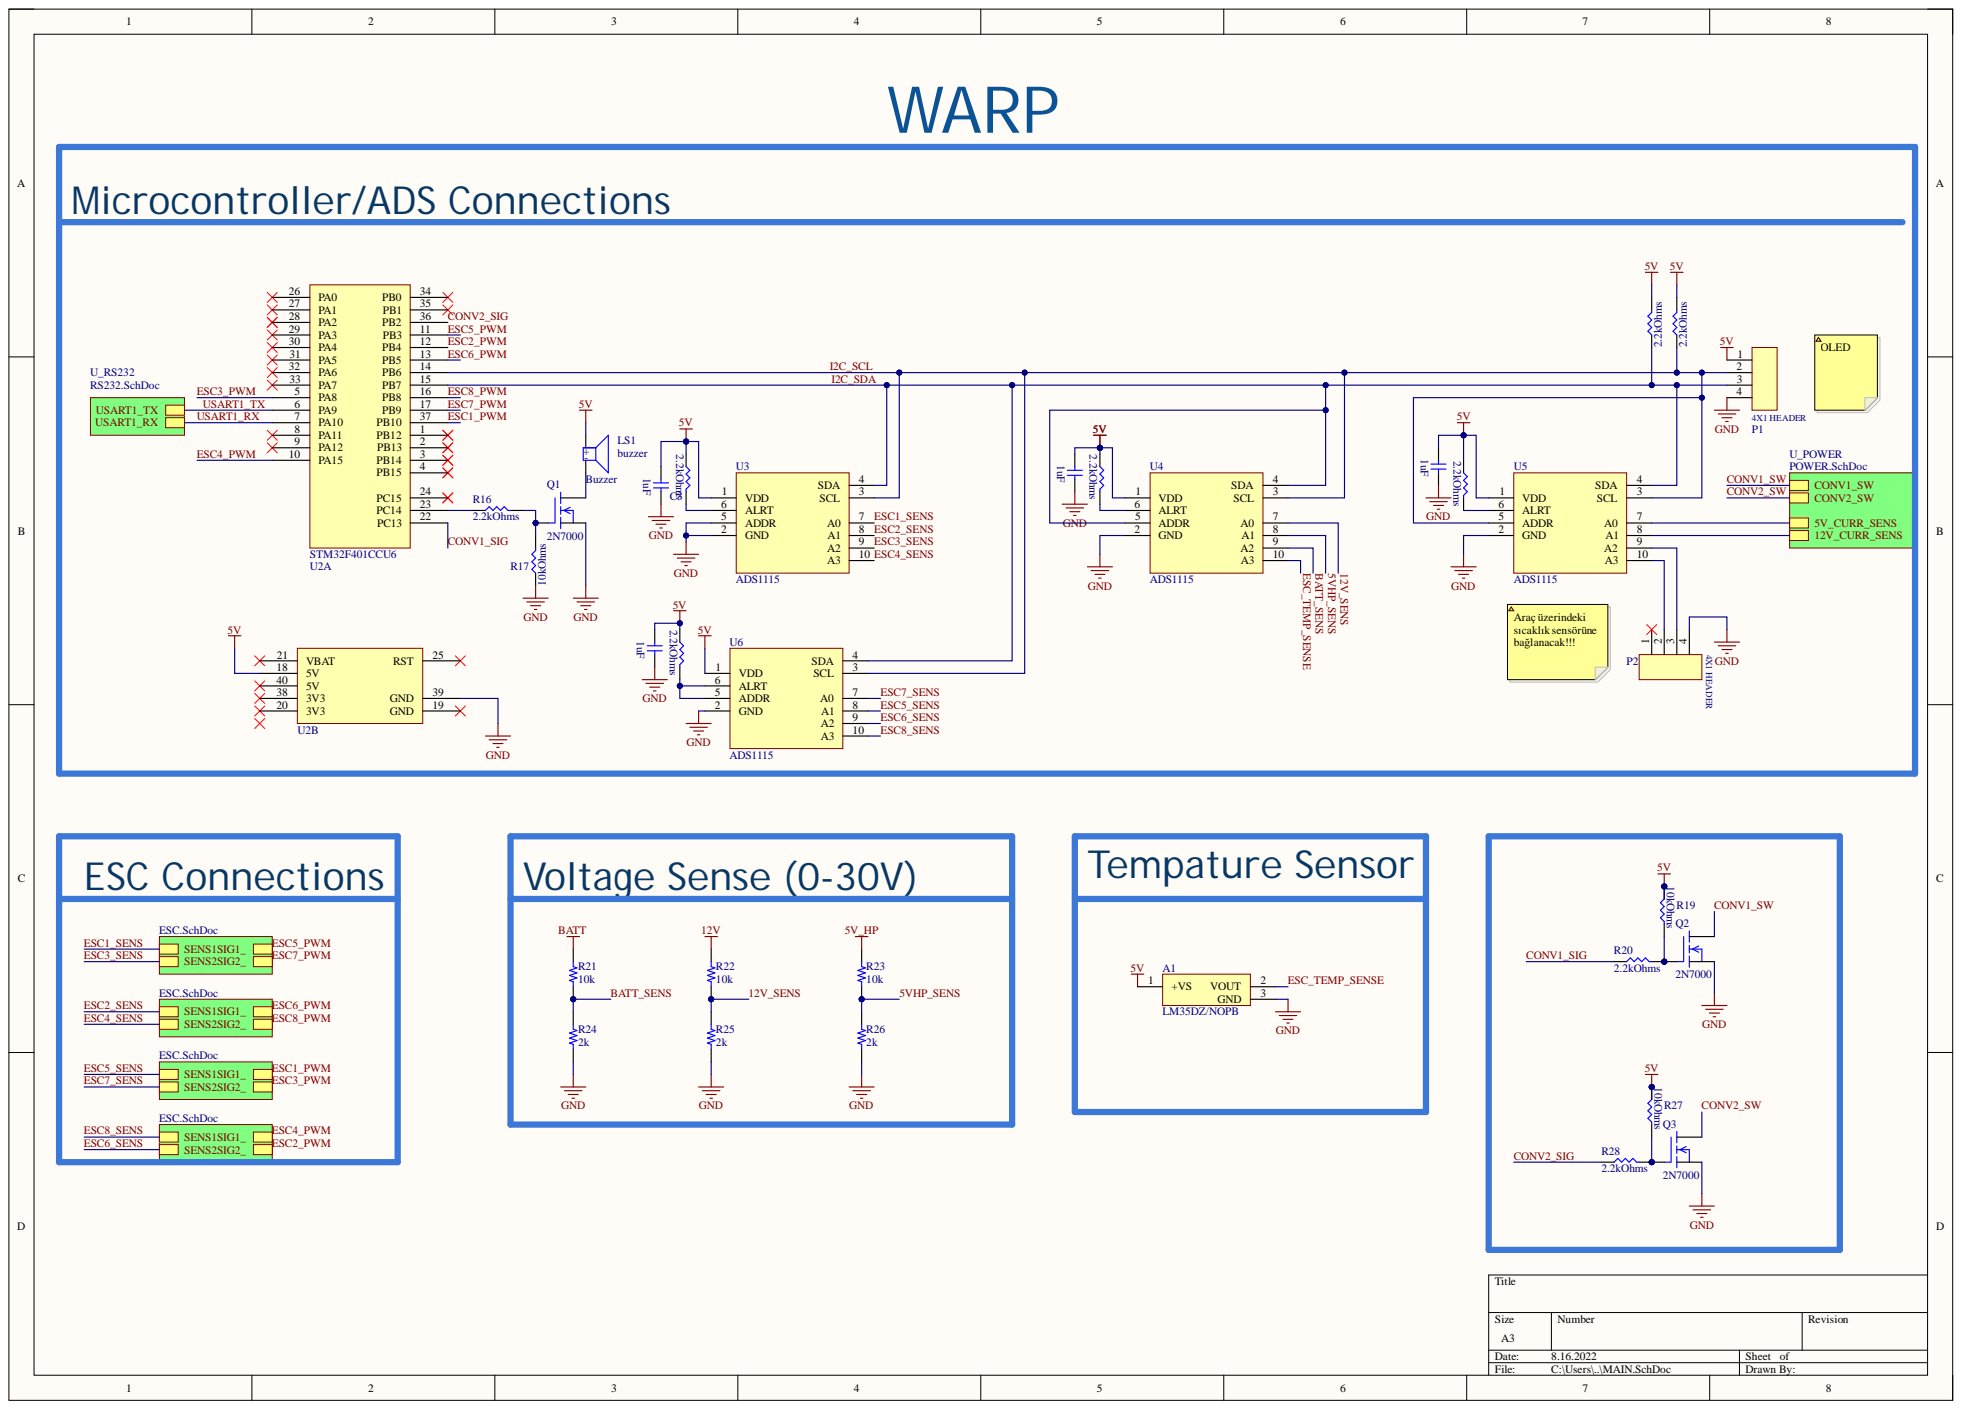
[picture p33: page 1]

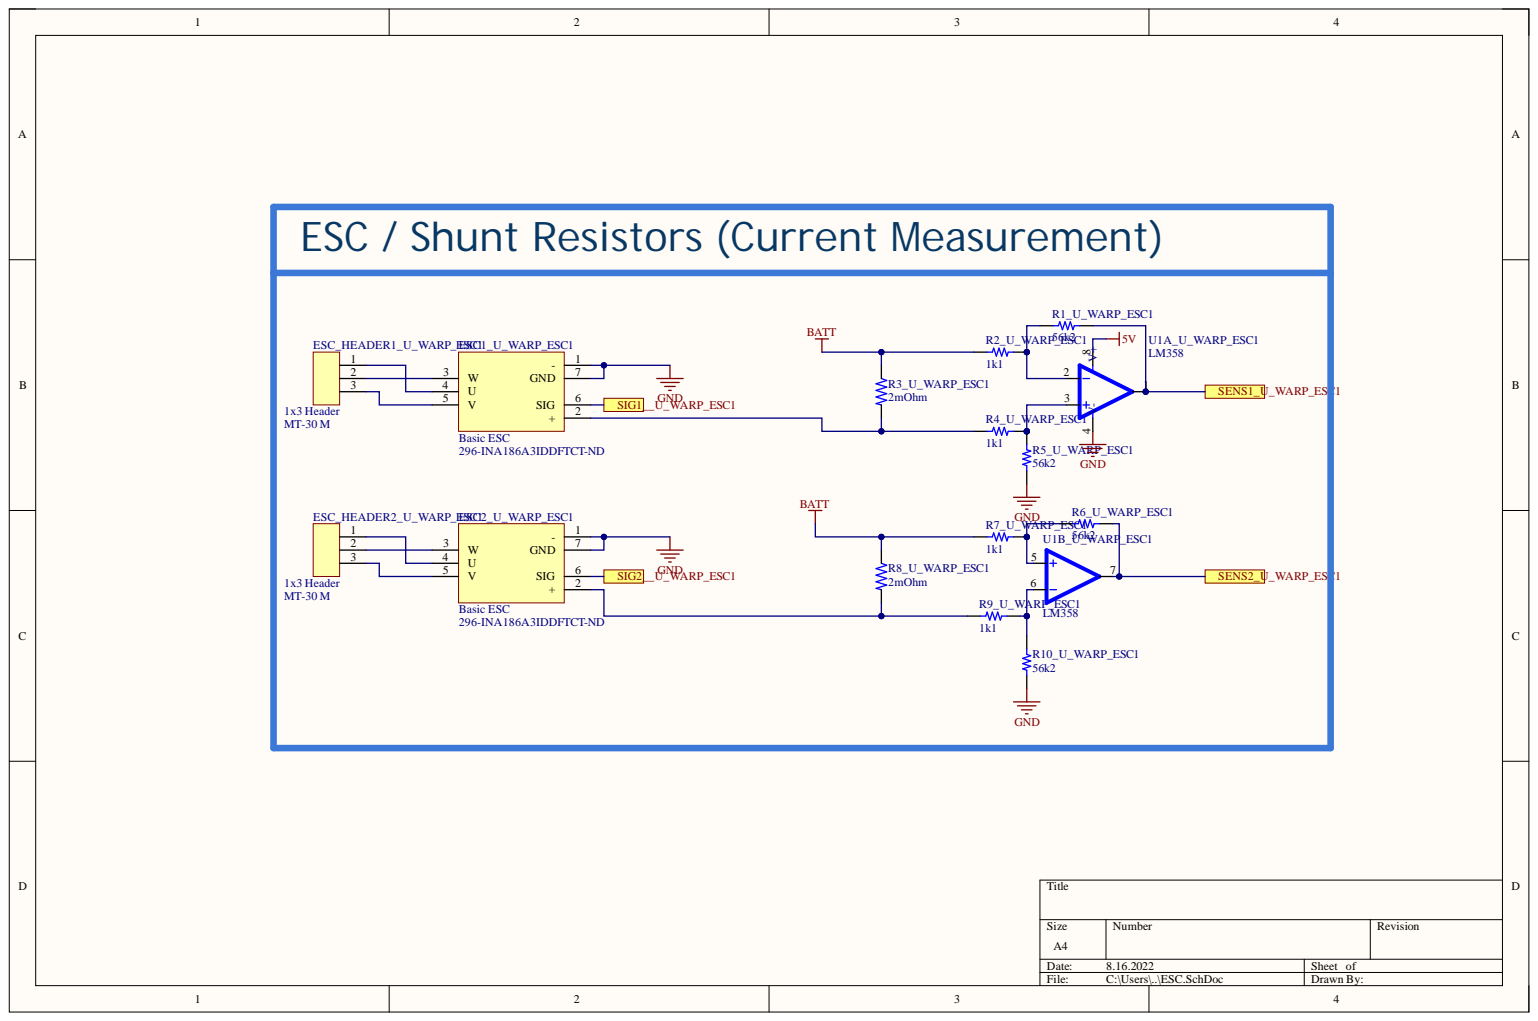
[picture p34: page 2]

ESC / Shunt Resistors (Current Measurement)

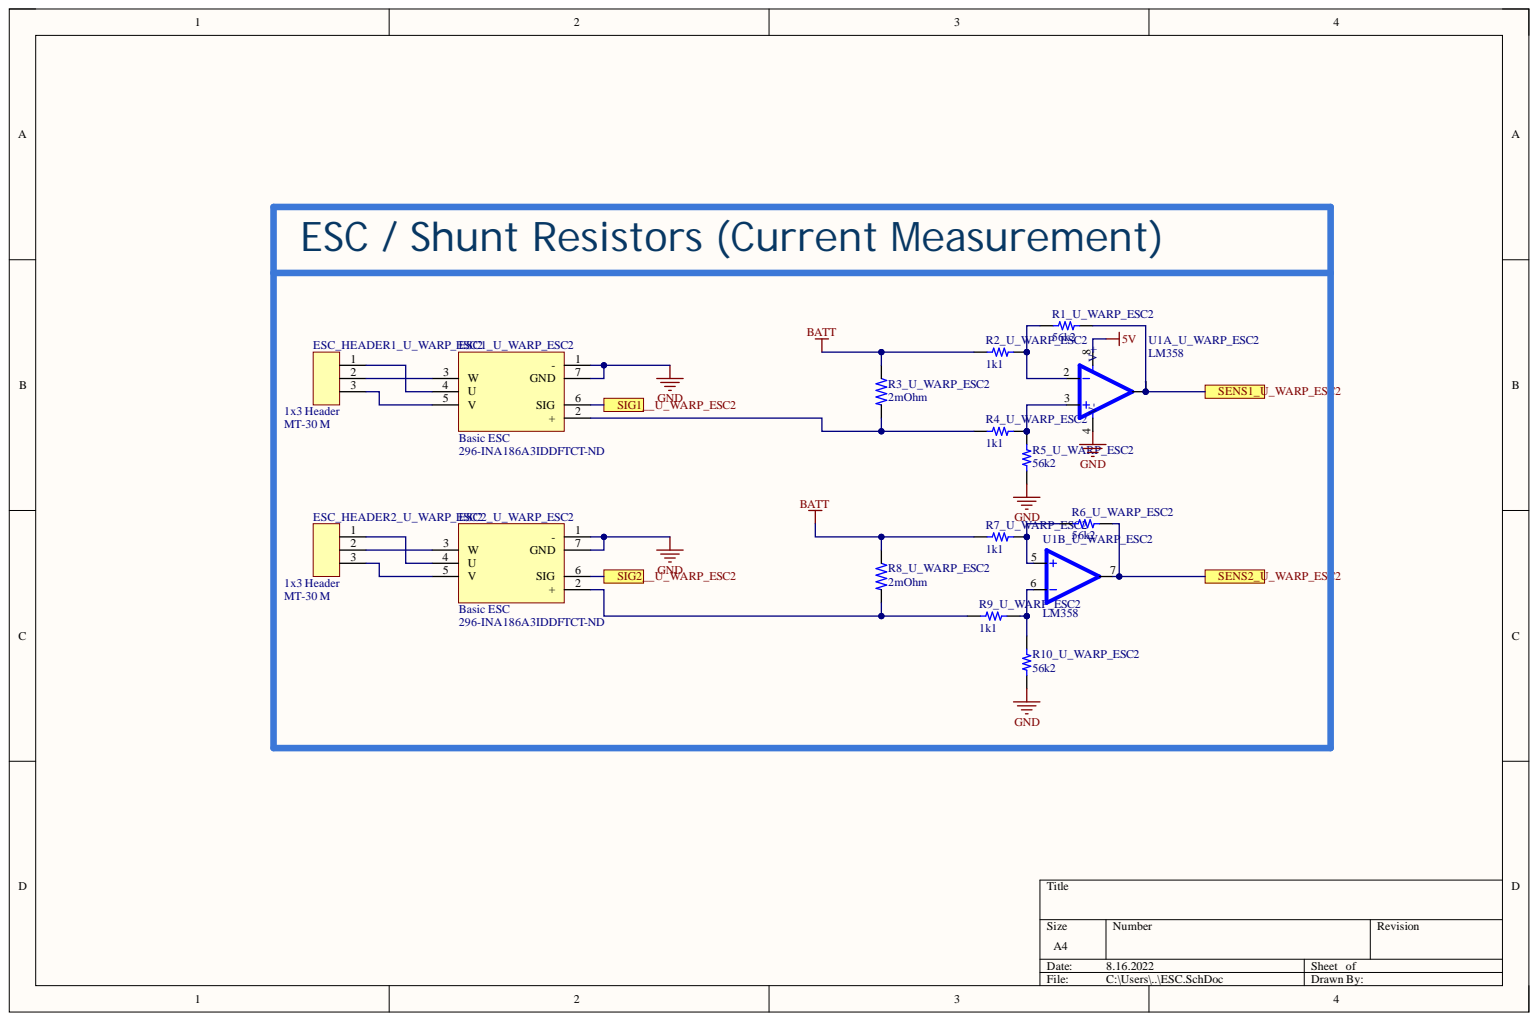
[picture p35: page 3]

ESC / Shunt Resistors (Current Measurement)

3 | U 4

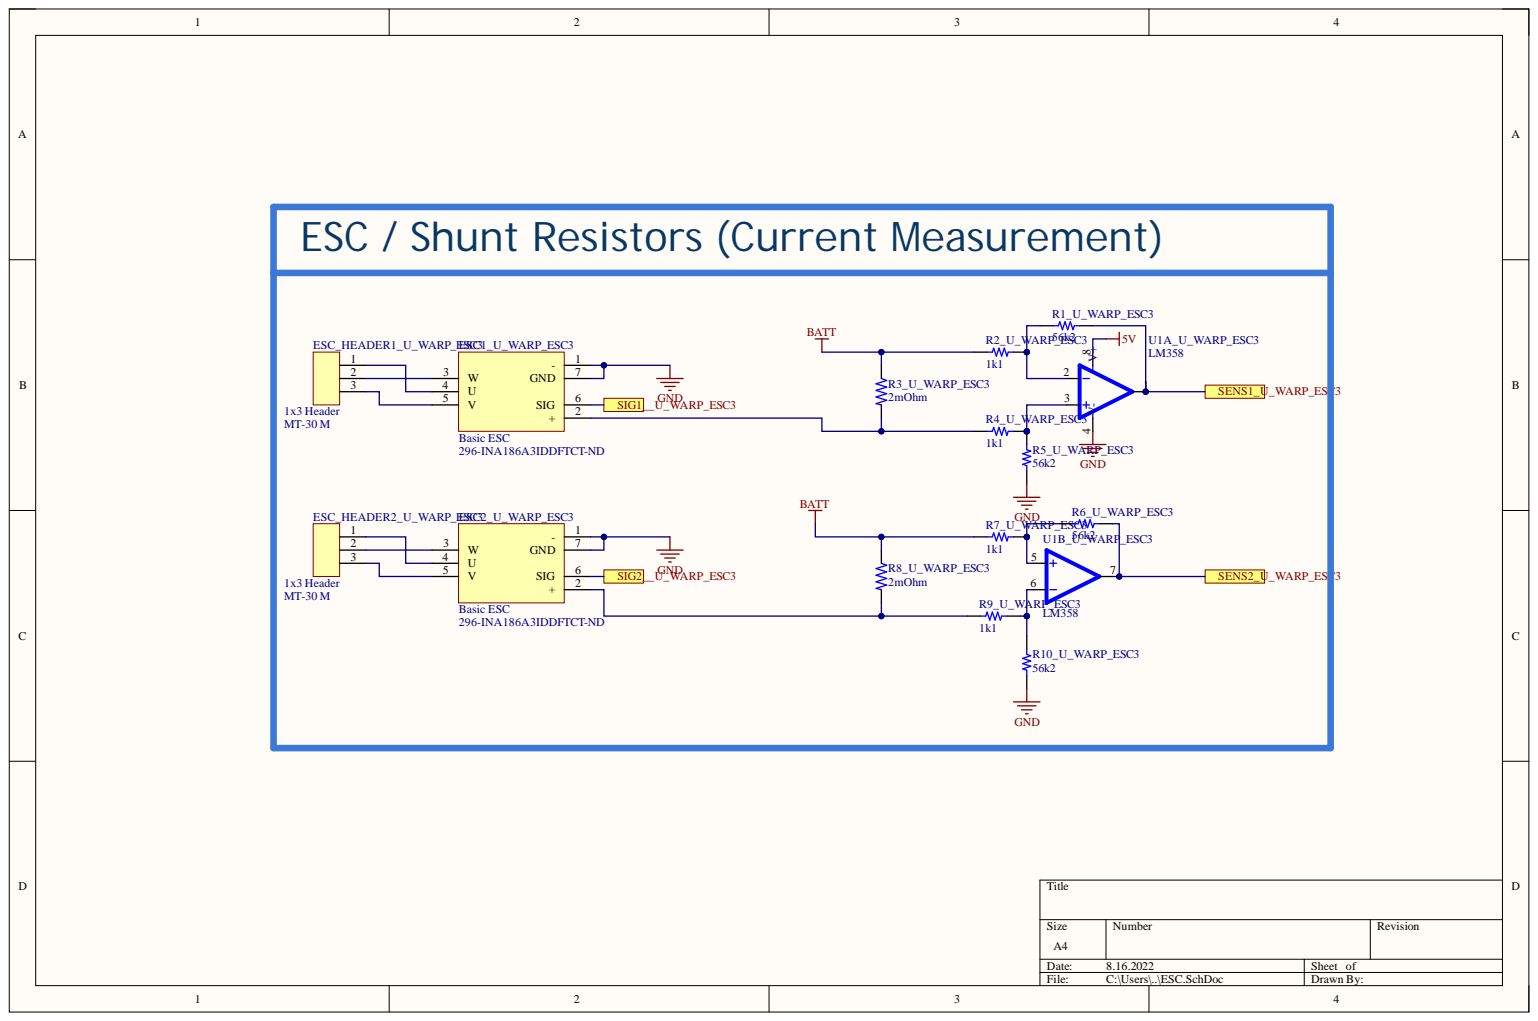
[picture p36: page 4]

ESC / Shunt Resistors (Current Measurement)

3 | U 4

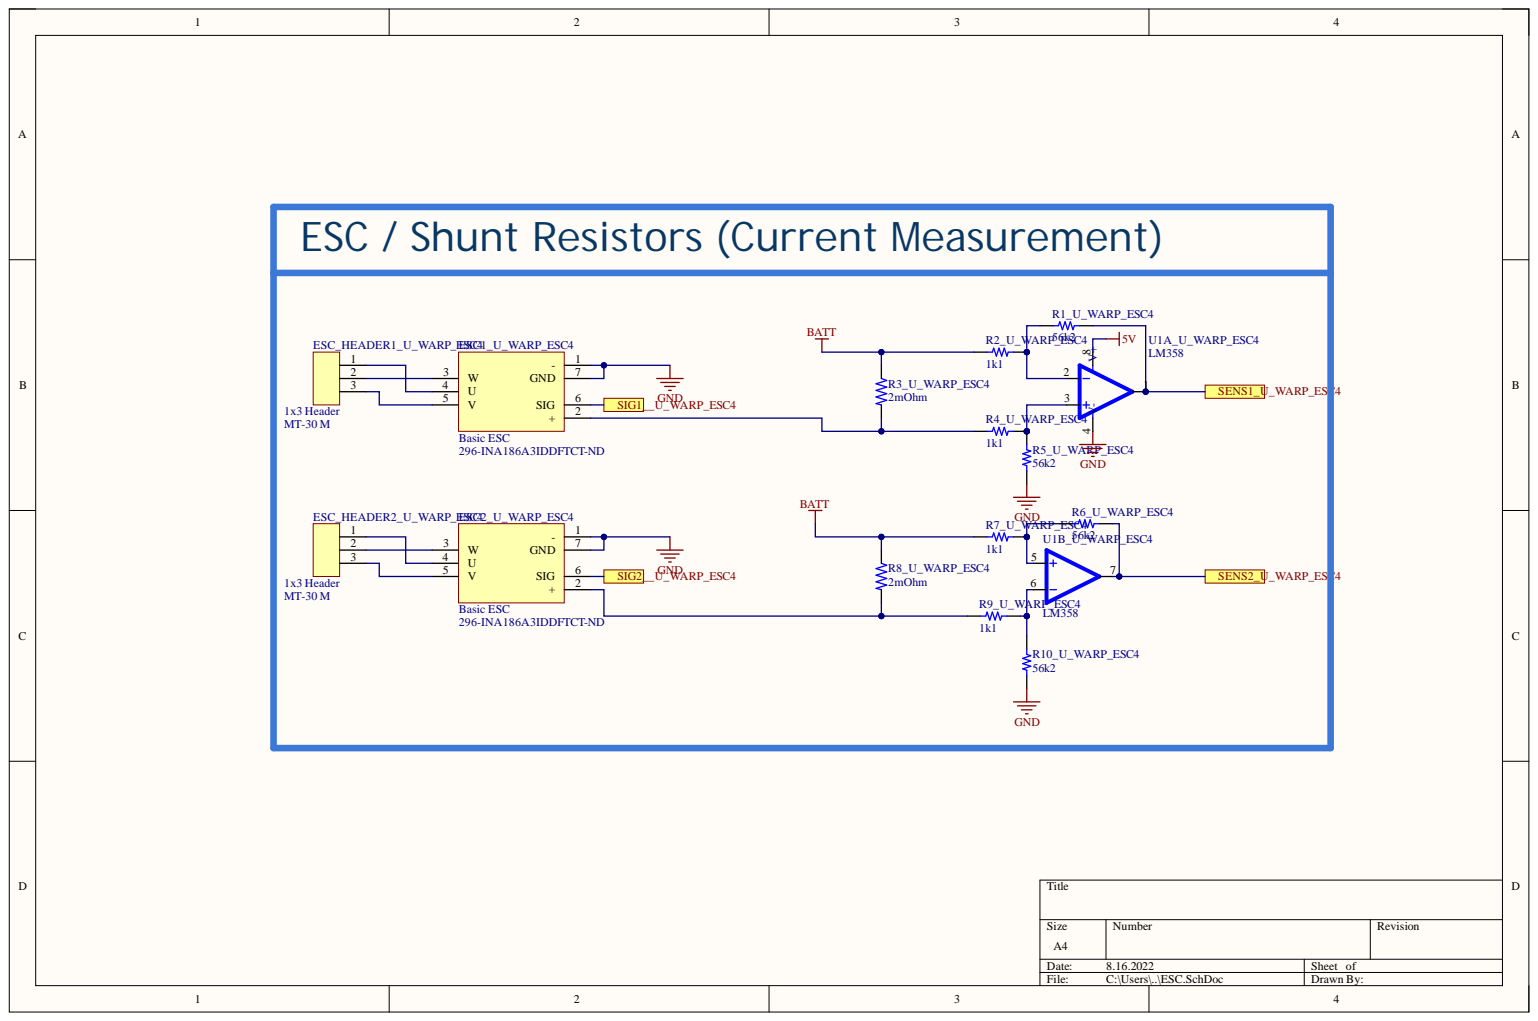
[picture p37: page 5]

ESC / Shunt Resistors (Current Measurement)

3 | U 4

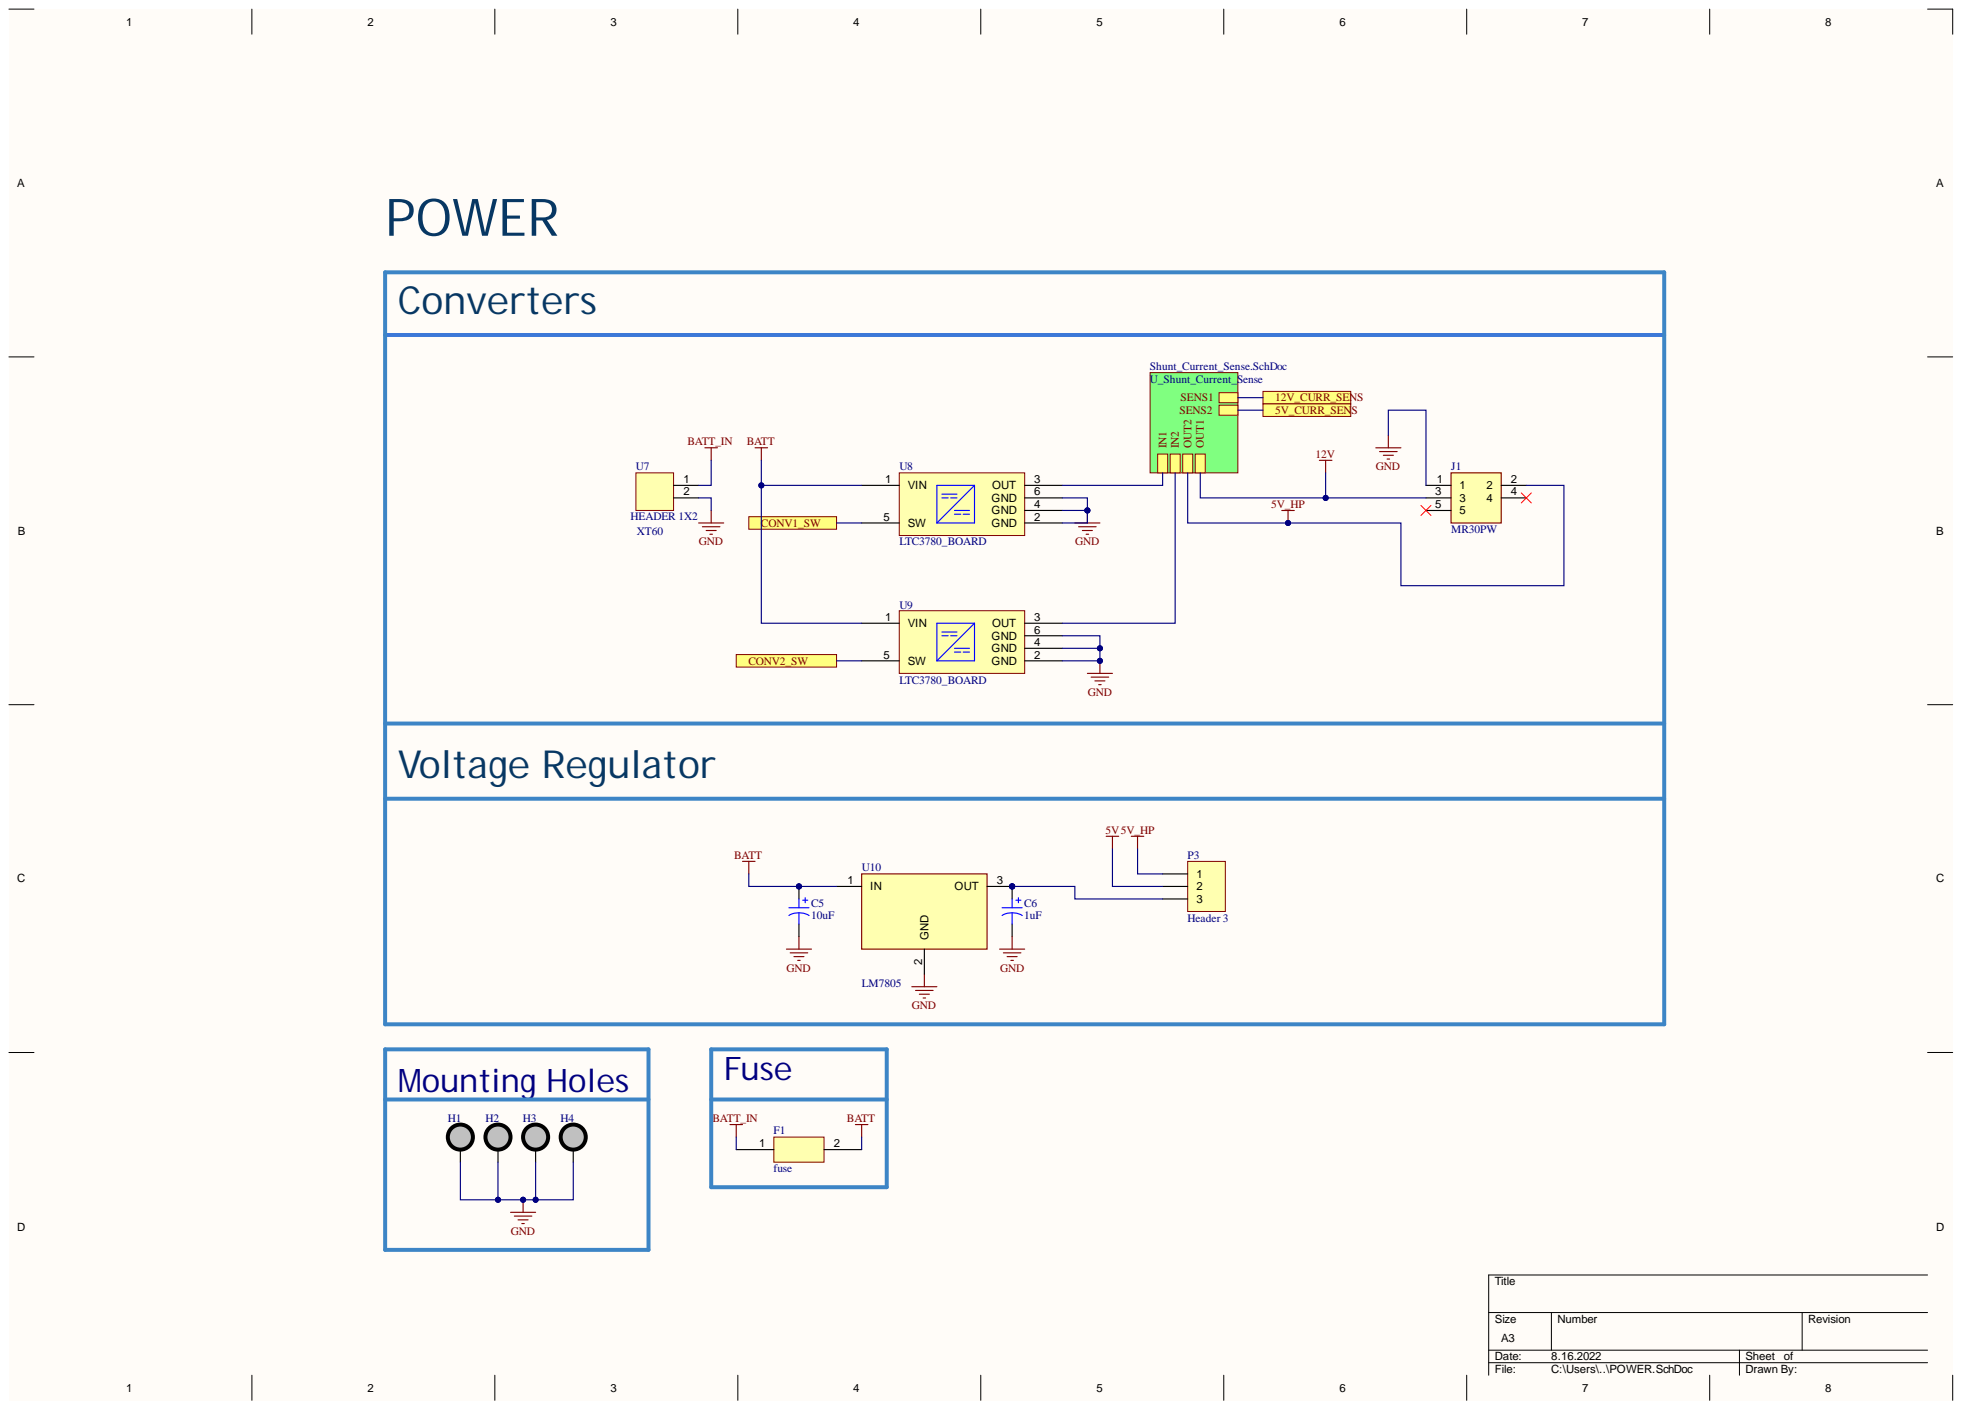
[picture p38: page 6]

CONV1_SW | MR30PW

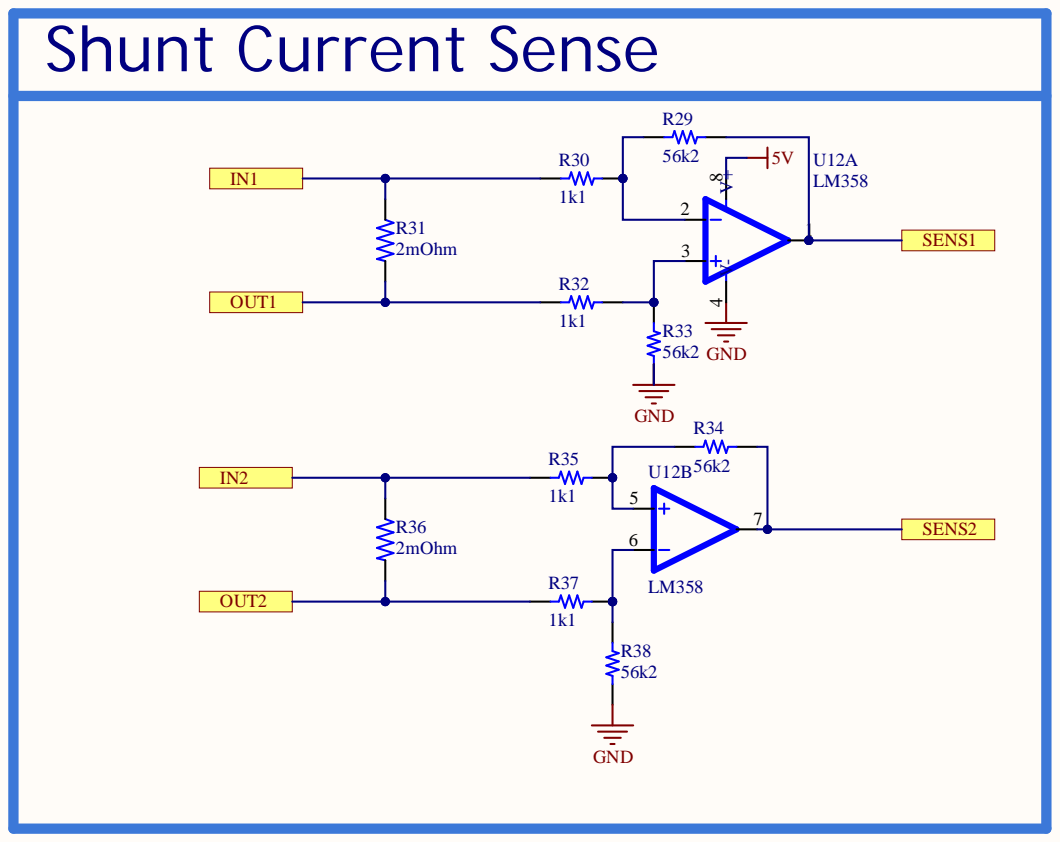
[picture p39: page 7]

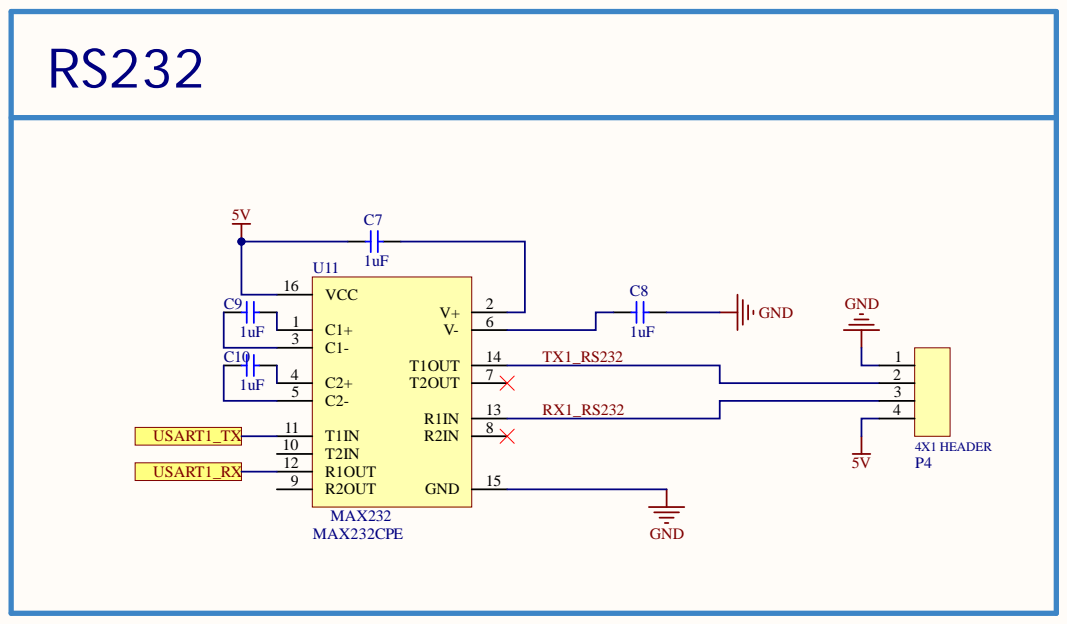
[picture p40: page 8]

VCC 16

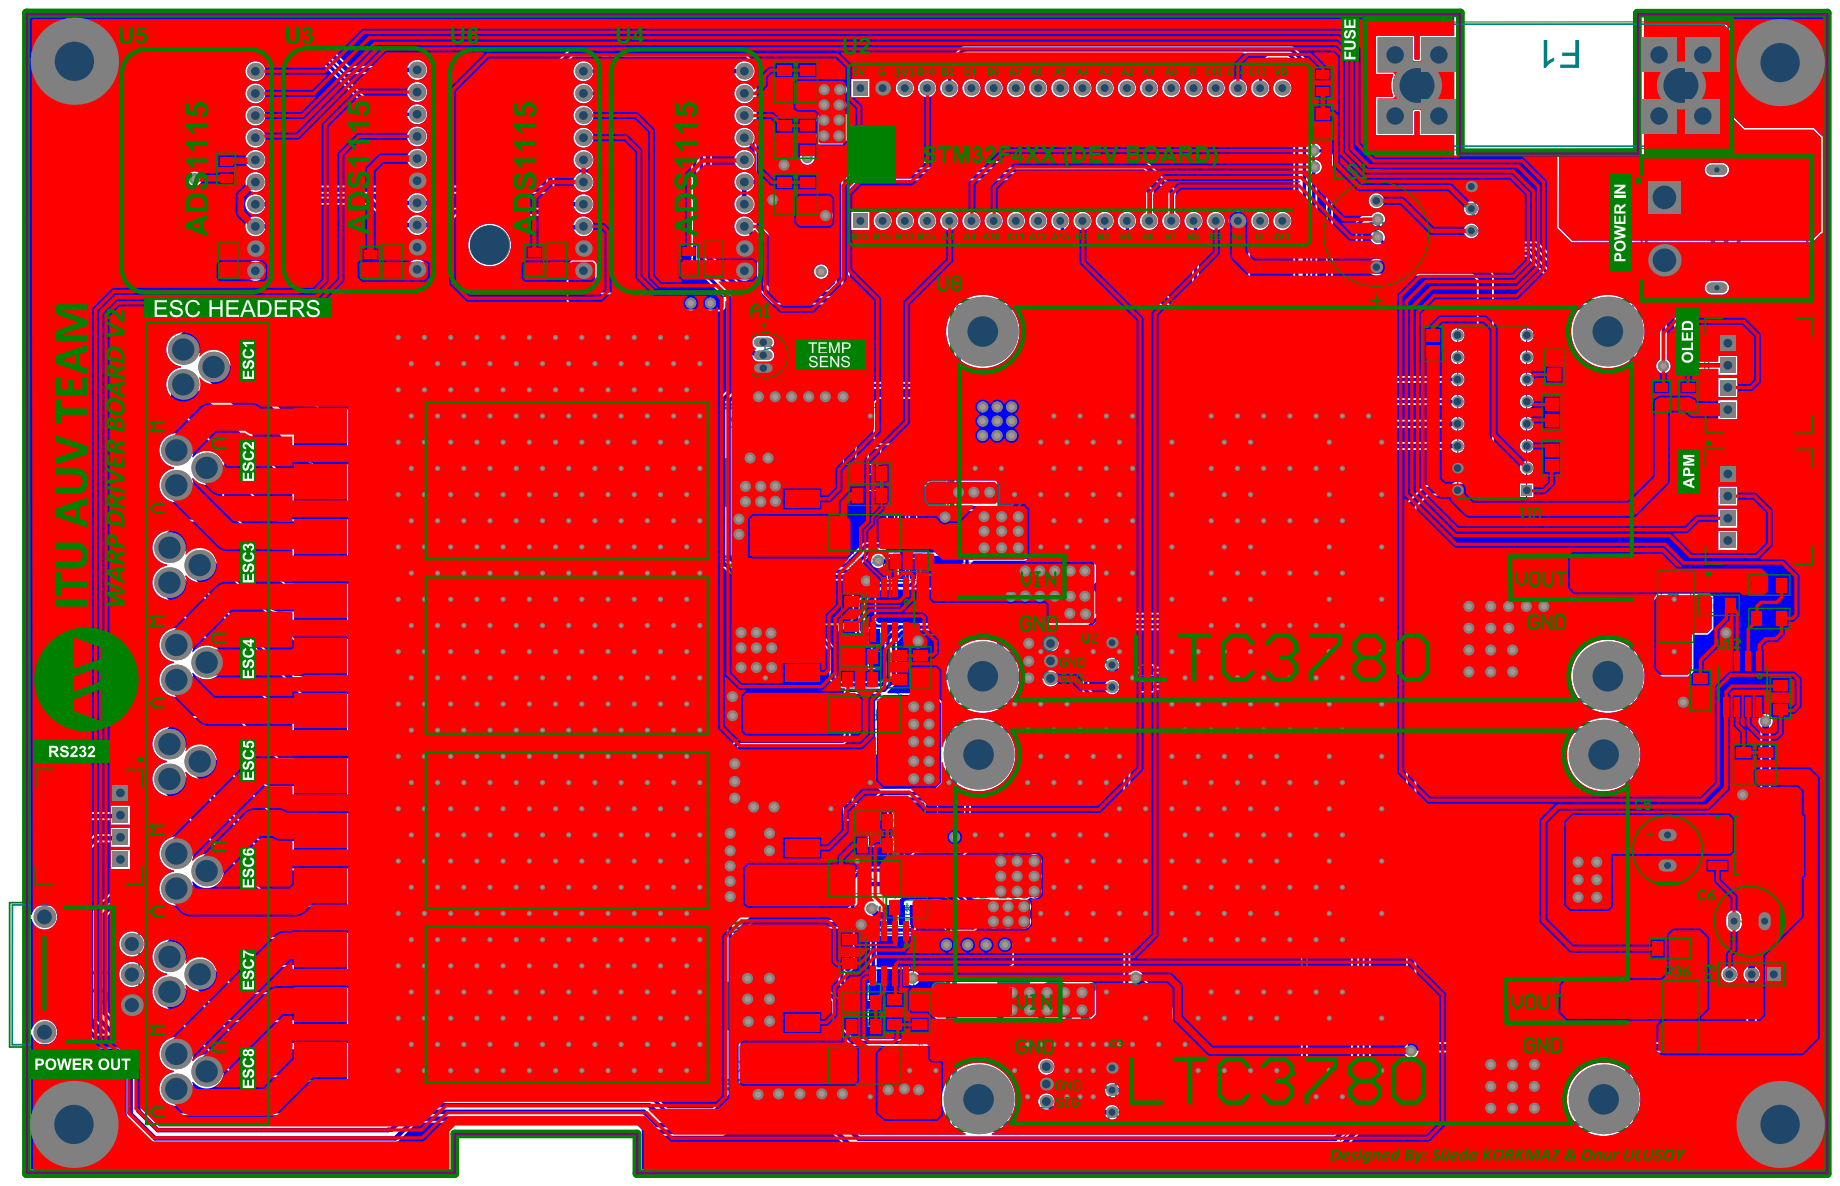
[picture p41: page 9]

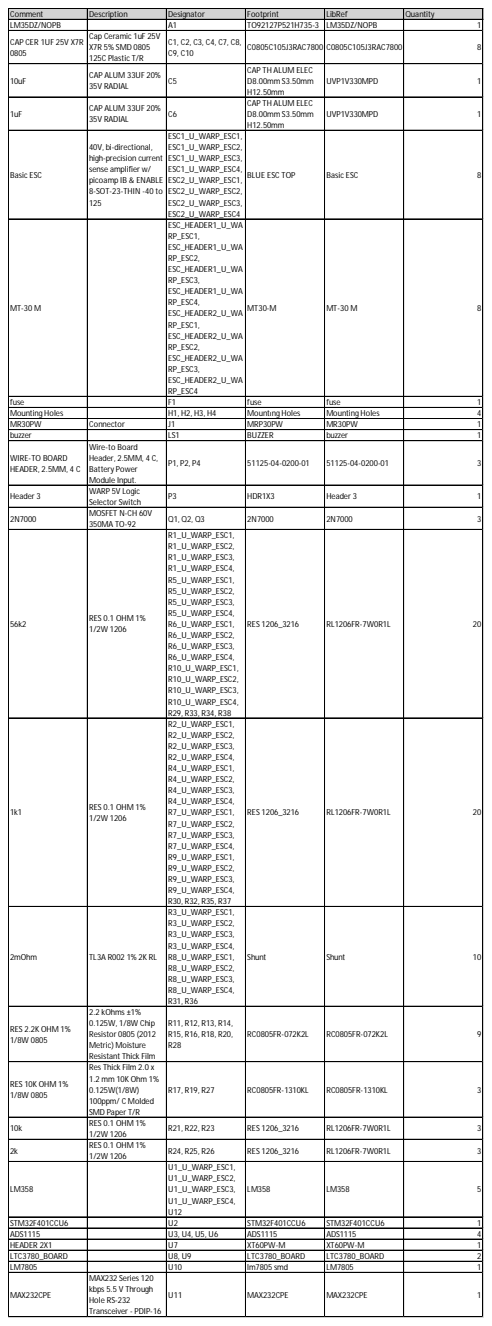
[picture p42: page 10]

Comment | Description | Designator | Footprint | LibRef | Quantity
LM35DZ/NOPB | | A1 | TO92127P521H735-3 | LM35DZ/NOPB | 1
CAP CER 1UF 25V X7R | Cap Ceramic 1uF 25V X7R 5% SMD 0805 125C Plastic T/R | C1, C2, C3, C4, C7, C8, C9, C10 | C0805C105J3RAC7800 | | 8

10uF | CAP ALUM 33UF 20% 35V RADIAL | C5 | CAP TH ALUM ELEC D8.00mm S3.50mm H12.50mm | UVP1V330MPD | 1

1uF | CAP ALUM 33UF 20% 35V RADIAL | C6 | CAP TH ALUM ELEC D8.00mm S3.50mm H12.50mm | UVP1V330MPD | 1

Basic ESC | 40V, bi-directional, high-precision current sense amplifier w/ picoamp IB & ENABLE 8-SOT-23-THIN -40 to 125 | ESC1_U_WARP_ESC1, ESC1_U_WARP_ESC2, ESC1_U_WARP_ESC3, ESC1_U_WARP_ESC4, ESC2_U_WARP_ESC1, ESC2_U_WARP_ESC2, ESC2_U_WARP_ESC3, ESC2_U_WARP_ESC4 | BLUE ESC TOP | Basic ESC | 8

MT-30 M | | ESC_HEADER1_U_WA RP_ESC1, ESC_HEADER1_U_WA RP_ESC2, ESC_HEADER1_U_WA RP_ESC3, ESC_HEADER1_U_WA RP_ESC4, ESC_HEADER2_U_WA RP_ESC1, ESC_HEADER2_U_WA RP_ESC2, ESC_HEADER2_U_WA RP_ESC3, ESC_HEADER2_U_WA RP_ESC4 | MT30-M | MT-30 M | 8

fuse | | F1 | fuse | fuse | 1
Mounting Holes | | H1, H2, H3, H4 | Mountıng Holes | Mounting Holes | 4
MR30PW | Connector | J1 | MRP30PW | MR30PW | 1
buzzer | | LS1 | BUZZER | buzzer | 1
WIRE-TO BOARD HEADER, 2.5MM, 4 C | Wire-to Board Header, 2.5MM, 4 C, Battery Power Module Input. | P1, P2, P4 | 51125-04-0200-01 | 51125-04-0200-01 | 3

Header 3 | WARP 5V Logic Selector Switch | P3 | HDR1X3 | Header 3 | 1

2N7000 | MOSFET N-CH 60V 350MA TO-92 | Q1, Q2, Q3 | 2N7000 | 2N7000 | 3

56k2 | RES 0.1 OHM 1% 1/2W 1206 | R1_U_WARP_ESC1, R1_U_WARP_ESC2, R1_U_WARP_ESC3, R1_U_WARP_ESC4, R5_U_WARP_ESC1, R5_U_WARP_ESC2, R5_U_WARP_ESC3, R5_U_WARP_ESC4, R6_U_WARP_ESC1, R6_U_WARP_ESC2, R6_U_WARP_ESC3, R6_U_WARP_ESC4, R10_U_WARP_ESC1, R10_U_WARP_ESC2, R10_U_WARP_ESC3, R10_U_WARP_ESC4, R29, R33, R34, R38 | RES 1206_3216 | RL1206FR-7W0R1L | 20

1k1 | RES 0.1 OHM 1% 1/2W 1206 | R2_U_WARP_ESC1, R2_U_WARP_ESC2, R2_U_WARP_ESC3, R2_U_WARP_ESC4, R4_U_WARP_ESC1, R4_U_WARP_ESC2, R4_U_WARP_ESC3, R4_U_WARP_ESC4, R7_U_WARP_ESC1, R7_U_WARP_ESC2, R7_U_WARP_ESC3, R7_U_WARP_ESC4, R9_U_WARP_ESC1, R9_U_WARP_ESC2, R9_U_WARP_ESC3, R9_U_WARP_ESC4, R30, R32, R35, R37 | RES 1206_3216 | RL1206FR-7W0R1L | 20

2mOhm | TL3A R002 1% 2K RL | R3_U_WARP_ESC1, R3_U_WARP_ESC2, R3_U_WARP_ESC3, R3_U_WARP_ESC4, R8_U_WARP_ESC1, R8_U_WARP_ESC2, R8_U_WARP_ESC3, R8_U_WARP_ESC4, R31, R36 | Shunt | Shunt | 10

RES 2.2K OHM 1% 1/8W 0805 | 2.2 kOhms ±1% 0.125W, 1/8W Chip Resistor 0805 (2012 Metric) Moisture Resistant Thick Film | R11, R12, R13, R14, R15, R16, R18, R20, R28 | RC0805FR-072K2L | RC0805FR-072K2L | 9

RES 10K OHM 1% 1/8W 0805 | Res Thick Film 2.0 x 1.2 mm 10K Ohm 1% 0.125W(1/8W) 100ppm/ C Molded SMD Paper T/R | R17, R19, R27 | RC0805FR-1310KL | RC0805FR-1310KL | 3

10k | RES 0.1 OHM 1% 1/2W 1206 | R21, R22, R23 | RES 1206_3216 | RL1206FR-7W0R1L | 3

2k | RES 0.1 OHM 1% 1/2W 1206 | R24, R25, R26 | RES 1206_3216 | RL1206FR-7W0R1L | 3

LM358 | | U1_U_WARP_ESC1, U1_U_WARP_ESC2, U1_U_WARP_ESC3, U1_U_WARP_ESC4, U12 | LM358 | LM358 | 5

STM32F401CCU6 | | U2 | STM32F401CCU6 | STM32F401CCU6 | 1
ADS1115 | | U3, U4, U5, U6 | ADS1115 | ADS1115 | 4
HEADER 2X1 | | U7 | XT60PW-M | XT60PW-M | 1
LTC3780_BOARD | | U8, U9 | LTC3780_BOARD | LTC3780_BOARD | 2
LM7805 | | U10 | lm7805 smd | LM7805 | 1
MAX232CPE | MAX232 Series 120 kbps 5.5 V Through Hole RS-232 Transceiver - PDIP-16 | U11 | MAX232CPE | MAX232CPE | 1

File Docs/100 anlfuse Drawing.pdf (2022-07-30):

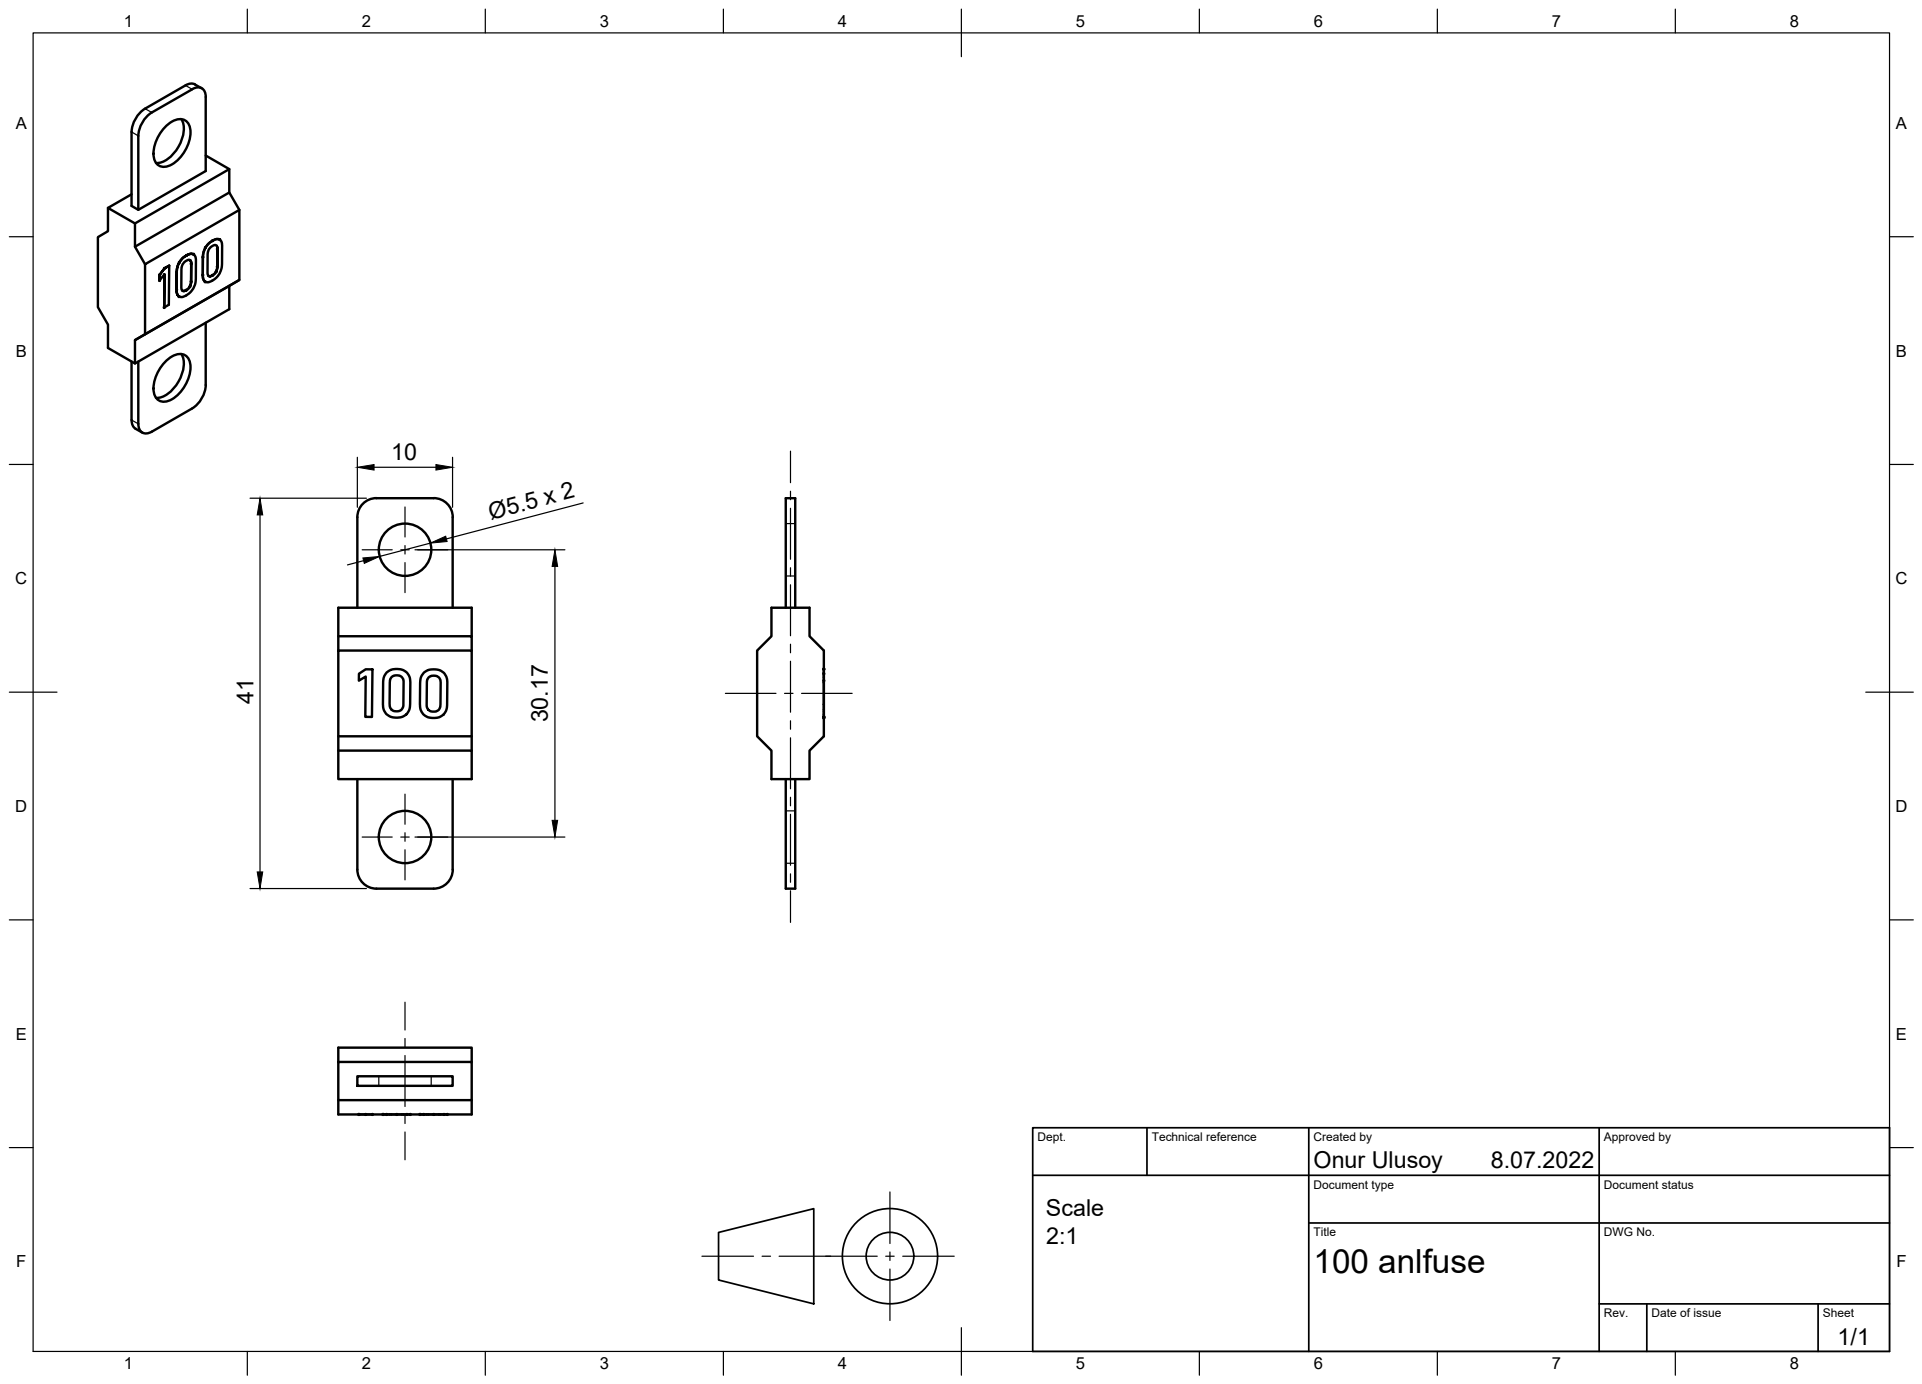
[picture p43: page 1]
Title; DWG No.; Rev.; Date of issue; Sheet; 100 anlfuse; Onur Ulusoy 41

Dept. | Technical reference | Created by 8.07.2022 | Approved by

Document type | Document status

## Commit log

2022-01-05 Add basic connector 3D models
    [JST-B10B-EH-A.STEP, JST-B11B-EH-A.STEP, JST-B12B-EH-A.STEP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]
2022-01-15 Include additional power connector 3D models
    [Male Header v4.step, mr30pw-m connector v2.step]
2022-02-05 Add MT30 and XT60 power connectors 3D models
    [XT60PW-M connector v1.step, mt30-m connector v2.step]
2022-02-16 Integrate SMD resistor 3D model
    [resistor_smd_1206 v13.step]
2022-03-01 Embed SMD LED 3D model
    [SMD_0805LED_YEL v2.step]
2022-04-27 Insert Converter and Bluerobotics ESC 3D models
    [BESC30-R3 v1.step]
2022-05-01 Include crucial PcbLib to facilitate PCB development
2022-06-01 Establish project core with MAIN schematic
    [MAIN.SchDoc]
2022-06-04 Integrate RS232
    [RS232.SchDoc]
2022-06-04 Consolidate knowledge on pin numbers as of 4.06.22
2022-06-07 Augment design with the Shunt Current Sense schematic for precise power monitoring
    [Shunt_Current_Sense.SchDoc]
2022-06-10 Include POWER schematic to manage energy flows
    [POWER.SchDoc]
2022-06-12 Include STM32F401 Board 3D model
    [stm32f401 v2.step]
2022-06-15 Integrate the ESC schematic
    [ESC.SchDoc]
2022-06-23 Launch Altium project with WARP.PrjPcb file
    [WARP.PrjPcb]
2022-06-23 Step into the world of physical realization with WARP PCB design file
2022-06-23 Provide shunt voltage amplifier simulation data for thorough circuit analysis
2022-07-01 Provide clarity for manufacturing by adding fuse component drawing
2022-07-04 Visualize the complete schematic as of 17.08.22 for comprehensive understanding
2022-07-07 Incorporate fuse component image for realistic representation
2022-07-11 Upload the WARP PCB Change Report to track design progress
2022-07-12 Add fuse and its support 3D models
    [100 anlfuse v4.step, fuse support v1.step]
2022-07-22 Provide historical design views in 'Older Versions PCB Views' folder
2022-07-30 Illustrate the fuse assembly from left view for inspection
2022-07-30 Add fuse assembly image for detailed examination
2022-08-01 Include standalone versions of fuse assembly 3D models
    [fuse assembly no pcb no support v2.step, fuse assembly no pcb v2.step]
2022-08-03 Prepare for manufacturing with Gerber files for version 2
    [WARP.GBL, WARP.GBO, WARP.GBP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]
2022-08-06 Categorize 3D Model Library with seperate folders
    [100 anlfuse v4.step, BESC30-R3 v1.step, JST-B10B-EH-A.STEP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]
2022-08-10 Add ADCS and Power schematics pictures
2022-08-10 Insert full fuse assembly 3D model
    [fuse assembly v8.step]
2022-08-20 Add assembly pictures and perspective views of PCB
2022-09-01 Incorporate standoff assemblies 3D models
    [standoff assembly 2 v3.step, standoff assembly v10.step]
2022-09-05 Write board description
2022-09-13 Add primary stage protection strategies to README
2022-09-15 Add images and gifs showing top view of PCB
2022-09-18 Write second stage protection explanations
2022-09-25 Write ESC Integration and cooling parts to README
2022-09-28 Include perspective back view of the PCB and connection diagram
2022-10-07 Add images of fuse and interactive turnable HTML
2022-10-10 Include WARP pcb video
